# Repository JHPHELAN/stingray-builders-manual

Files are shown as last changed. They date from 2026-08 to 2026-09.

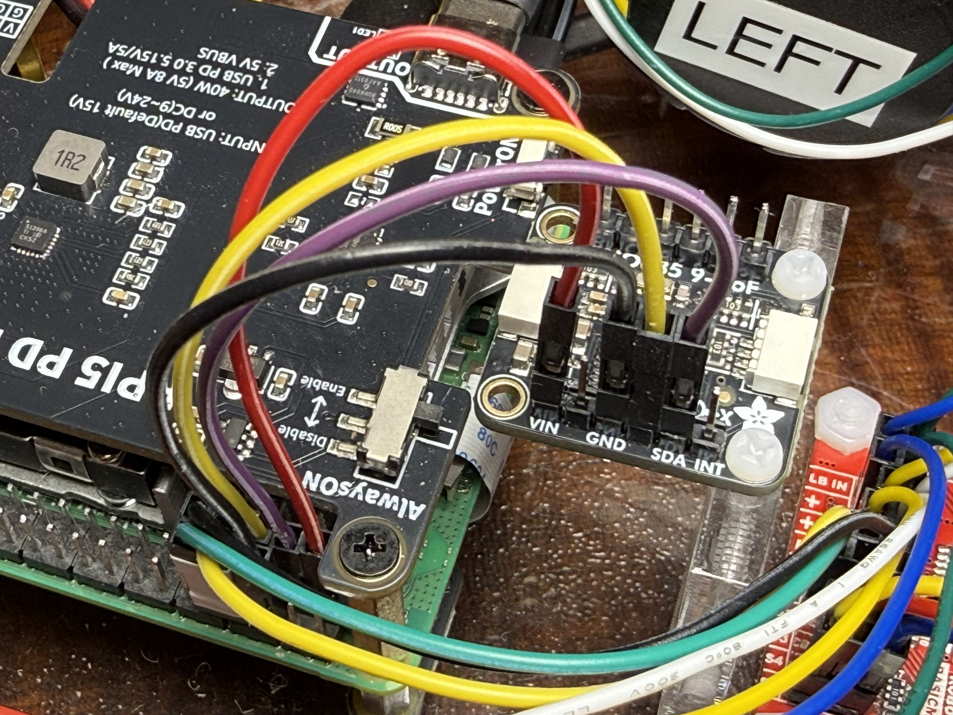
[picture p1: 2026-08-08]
images/BNO085 Wiring.jpg

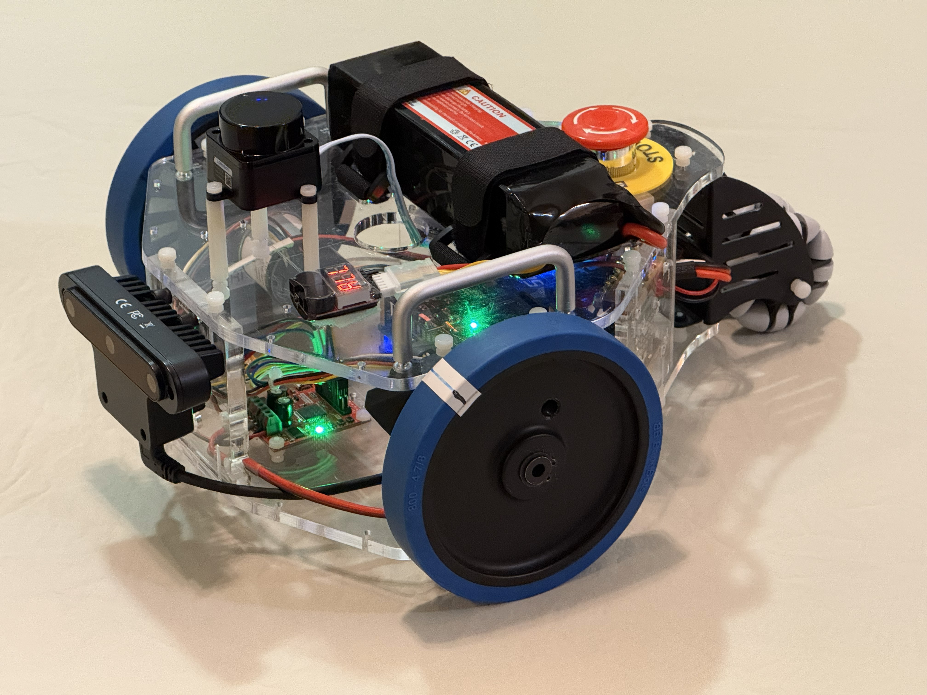
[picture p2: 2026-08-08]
images/Stormy Portrait angle.jpg

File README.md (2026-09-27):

# Stormy the Stingray - Builder's Manual

Version 1.2 - Compiled 2026-07-20; public release 2026-09-11;
amended 2026-09-21 (right rear Power Input Panel hardware caught
up: Ch 3.1 rewritten, FN 22 gains DMM verification sub-section and
15SQ045 diode part swap, Appendix G.9 schematic bumped to
2026.09.20).

If the SD card dies tomorrow, this document is how Stormy gets rebuilt.
Present-tense, imperative, subsystem-oriented.  Every procedure is one
that has been executed successfully on the real robot.

- **Owner:** James H Phelan, MD (Humble, TX).
- **Status:** Public.  Values in `<ANGLE_BRACKETS>` throughout are
  placeholders for reader-specific local values (LAN IPs, SSIDs, MAC
  addresses, house dimensions, dock offsets).  See the "Placeholder
  key" block in [`Stingray_Builders_Manual.txt`](Stingray_Builders_Manual.txt).
- **License:** CC BY 4.0 (see [License](#license) at the bottom).

## Companion files in this repo

| File | Purpose |
| --- | --- |
| [`Stingray_Builders_Manual.txt`](Stingray_Builders_Manual.txt) | **Source of truth.** Plain-text master copy of this document.  All edits go here first; `README.md` is regenerated from it (see [Regenerating this README](#regenerating-this-readme)). |
| [`Stingray_Field_Notes.txt`](Stingray_Field_Notes.txt) | 105 numbered lessons + indexes distilled from the source log.  Cited throughout the Manual by item number. |
| [`Stingray_Curation_Notes.txt`](Stingray_Curation_Notes.txt) | 17 chunks of raw stardated distillate from the source log.  Background material for the Manual. |
| [`kicad/Stingray/`](kicad/Stingray/) | KiCad 10.0 project - schematic, custom symbol library, PCB stub.  Source for Appendix [G.9](#g9--stormy-schematic-20260920png). |
| [`images/`](images/) | Diagrams and photos catalogued in [Appendix G](#appendix-g---diagrams-and-photos). |
| [`tools/build_readme.py`](tools/build_readme.py) | Regenerates this `README.md` from the `.txt`. |
| [`LICENSE`](LICENSE) | CC BY 4.0 legal text. |

The source log (`Stingray Experience.wpd`, 832 pp WordPerfect) is
**not** in this repo -- it is the private working diary this Manual
and the two companion `.txt` files were distilled from.

## Companion repositories

The Manual references code and configuration living in these repos:

- **Build descriptor:** <https://github.com/JHPHELAN/stingray>
- **Software (main):** <https://github.com/JHPHELAN/articubot_one>
    - `jp` branch -- main software (fork of slgrobotics's fork of
      Articulated Robotics' `articubot_one`)
    - `exploration` branch -- house exploration + mapping code
      (currently running on Stormy; not yet merged to `jp`)
- **Motor driver:** <https://github.com/JHPHELAN/roboclaw_driver>
    (fork of wimblerobotics/roboclaw_driver)
- **Dotfiles (private):** <https://github.com/JHPHELAN/stingray-dotfiles>

## Regenerating this README

`Stingray_Builders_Manual.txt` is the source of truth.  `README.md`
is mechanically generated from it by
[`tools/build_readme.py`](tools/build_readme.py).  To port a `.txt`
edit into the rendered manual:

```bash
python3 tools/build_readme.py
```

Then commit both files together.

## Table of contents

- [CHAPTER 0 - HOW TO USE THIS MANUAL](#chapter-0---how-to-use-this-manual)
- [CHAPTER 1 - ORIGIN](#chapter-1---origin)
- [CHAPTER 2 - CURRENT HARDWARE SUMMARY](#chapter-2---current-hardware-summary)
  - [2.1  Physical dimensions and mass](#21--physical-dimensions-and-mass)
  - [2.2  Power (see Chapter 3)](#22--power-see-chapter-3)
  - [2.3  Drivetrain (see Chapter 4)](#23--drivetrain-see-chapter-4)
  - [2.4  Compute (see Chapter 5)](#24--compute-see-chapter-5)
  - [2.5  IMU (see Chapter 6)](#25--imu-see-chapter-6)
  - [2.6  LiDAR (see Chapter 7)](#26--lidar-see-chapter-7)
  - [2.7  Camera (see Chapter 8)](#27--camera-see-chapter-8)
  - [2.8  Network (see Chapters 9 and 18)](#28--network-see-chapters-9-and-18)
- [CHAPTER 3 - POWER SYSTEM](#chapter-3---power-system)
  - [3.1  Topology (current, 2026-09-20)](#31--topology-current-2026-09-20)
  - [3.2  Emergency stop + remote kill switch (two distinct devices)](#32--emergency-stop--remote-kill-switch-two-distinct-devices)
  - [3.3  Shunt Regulator - Pololu 3779](#33--shunt-regulator---pololu-3779)
  - [3.4  Common power symptoms and fixes](#34--common-power-symptoms-and-fixes)
- [CHAPTER 4 - DRIVETRAIN](#chapter-4---drivetrain)
  - [4.1  Motors](#41--motors)
  - [4.2  Encoders](#42--encoders)
  - [4.3  Wiring - motors and encoders](#43--wiring---motors-and-encoders)
  - [4.4  RoboClaw configuration](#44--roboclaw-configuration)
  - [4.5  PID tuning](#45--pid-tuning)
  - [4.6  Driver package](#46--driver-package)
  - [4.7  Twist vs TwistStamped](#47--twist-vs-twiststamped)
  - [4.8  Per-board main-battery voltage calibration](#48--per-board-main-battery-voltage-calibration)
- [CHAPTER 5 - COMPUTE (Raspberry Pi 5)](#chapter-5---compute-raspberry-pi-5)
  - [5.1  Hardware](#51--hardware)
  - [5.2  UART configuration for RoboClaw](#52--uart-configuration-for-roboclaw)
  - [5.3  EEPROM and boot configuration](#53--eeprom-and-boot-configuration)
  - [5.4  Diagnostic commands (adopted from Sergei)](#54--diagnostic-commands-adopted-from-sergei)
- [CHAPTER 6 - IMU (BNO085)](#chapter-6---imu-bno085)
  - [6.1  Hardware](#61--hardware)
  - [6.2  Driver](#62--driver)
  - [6.3  Configuration](#63--configuration)
  - [6.4  EKF integration](#64--ekf-integration)
  - [6.5  Verification](#65--verification)
- [CHAPTER 7 - LIDAR (Youyeetoo FHL-LD19)](#chapter-7---lidar-youyeetoo-fhl-ld19)
  - [7.1  Hardware](#71--hardware)
  - [7.2  udev rule (persistent device name)](#72--udev-rule-persistent-device-name)
  - [7.3  Driver](#73--driver)
  - [7.4  Launch and static TF](#74--launch-and-static-tf)
  - [7.5  SLAM Toolbox / Nav2 usage](#75--slam-toolbox--nav2-usage)
- [CHAPTER 8 - CAMERA (Luxonis OAK-D)](#chapter-8---camera-luxonis-oak-d)
  - [8.1  Hardware](#81--hardware)
  - [8.2  Driver install](#82--driver-install)
  - [8.3  Configuration](#83--configuration)
  - [8.4  Nav2 obstacle source](#84--nav2-obstacle-source)
  - [8.5  Mesh and material](#85--mesh-and-material)
- [CHAPTER 9 - NETWORKING](#chapter-9---networking)
  - [9.1  Interfaces (current, 2026-07-20)](#91--interfaces-current-2026-07-20)
  - [9.2  Disabling wlan0](#92--disabling-wlan0)
  - [9.3  TP-Link Deco mesh layout](#93--tp-link-deco-mesh-layout)
  - [9.4  WiFi monitoring](#94--wifi-monitoring)
- [CHAPTER 10 - BASE OS INSTALL AND ROS 2 JAZZY SETUP](#chapter-10---base-os-install-and-ros-2-jazzy-setup)
  - [10.1  OS](#101--os)
  - [10.2  System updates and base tools](#102--system-updates-and-base-tools)
  - [10.3  UART configuration](#103--uart-configuration)
  - [10.4  ROS 2 Jazzy install](#104--ros-2-jazzy-install)
  - [10.5  ROS 2 environment vars](#105--ros-2-environment-vars)
  - [10.6  Additional apt packages needed](#106--additional-apt-packages-needed)
  - [10.7  SSH keys and Git](#107--ssh-keys-and-git)
- [CHAPTER 11 - WORKSPACE, REPOS, AND BUILD](#chapter-11---workspace-repos-and-build)
  - [11.1  Workspace layout](#111--workspace-layout)
  - [11.2  Clone all repos](#112--clone-all-repos)
  - [11.3  rosdep and build](#113--rosdep-and-build)
  - [11.4  Common build issues](#114--common-build-issues)
- [CHAPTER 12 - URDF AND ROBOT DESCRIPTION](#chapter-12---urdf-and-robot-description)
  - [12.1  Xacro file tree](#121--xacro-file-tree)
  - [12.2  Key physical dimensions (from stingray_properties.xacro)](#122--key-physical-dimensions-from-stingray_propertiesxacro)
  - [12.3  Wheel link split (RViz2 multi-visual bug workaround)](#123--wheel-link-split-rviz2-multi-visual-bug-workaround)
  - [12.4  base_footprint size (accounts for OAK-D nose)](#124--base_footprint-size-accounts-for-oak-d-nose)
  - [12.5  Mesh files](#125--mesh-files)
- [CHAPTER 13 - NAV2, SLAM TOOLBOX, AMCL CONFIGURATION](#chapter-13---nav2-slam-toolbox-amcl-configuration)
  - [13.1  Config files](#131--config-files)
  - [13.2  Nav2 footprint (polygon, 9-vertex)](#132--nav2-footprint-polygon-9-vertex)
  - [13.3  Heading overshoot fix (2026.04.12)](#133--heading-overshoot-fix-20260412)
  - [13.4  Costmap frequencies (Pi 5 tuning)](#134--costmap-frequencies-pi-5-tuning)
  - [13.5  KeepOut filter (for coffee-table zones)](#135--keepout-filter-for-coffee-table-zones)
  - [13.6  SLAM Toolbox](#136--slam-toolbox)
  - [13.7  AMCL (production localization)](#137--amcl-production-localization)
  - [13.8  Timestamp cache errors - diagnostic chain](#138--timestamp-cache-errors---diagnostic-chain)
- [CHAPTER 14 - MAPPING WORKFLOW (BLUEPRINT + HYBRID)](#chapter-14---mapping-workflow-blueprint--hybrid)
  - [14.1  The mapping problem](#141--the-mapping-problem)
  - [14.2  blueprint_to_pgm.py - one-time setup](#142--blueprint_to_pgmpy---one-time-setup)
  - [14.3  Room-by-room mapping cycle](#143--room-by-room-mapping-cycle)
  - [14.4  Loop closure discipline](#144--loop-closure-discipline)
  - [14.5  Loading and using the map for production nav](#145--loading-and-using-the-map-for-production-nav)
- [CHAPTER 15 - AUTONOMOUS EXPLORATION](#chapter-15---autonomous-exploration)
  - [15.1  Tool](#151--tool)
  - [15.2  Key parameters](#152--key-parameters)
  - [15.3  Known issue: cold-start deadlock](#153--known-issue-cold-start-deadlock)
  - [15.4  Usage](#154--usage)
- [CHAPTER 16 - INDICATORS](#chapter-16---indicators)
  - [16.1  Purpose](#161--purpose)
  - [16.2  Hardware (Rev 3, current)](#162--hardware-rev-3-current)
  - [16.3  Node](#163--node)
  - [16.4  WAV file preparation](#164--wav-file-preparation)
- [CHAPTER 17 - THREE-MACHINE OPERATION](#chapter-17---three-machine-operation)
  - [17.1  Machines](#171--machines)
  - [17.2  Standard launch order](#172--standard-launch-order)
  - [17.3  Common gotchas](#173--common-gotchas)
- [CHAPTER 18 - CYCLONEDDS UNICAST PEER DISCOVERY](#chapter-18---cyclonedds-unicast-peer-discovery)
  - [18.1  Why this exists](#181--why-this-exists)
  - [18.2  Config file](#182--config-file)
  - [18.3  Environment](#183--environment)
  - [18.4  Adding a third host](#184--adding-a-third-host)
- [CHAPTER 19 - DAILY OPERATIONS](#chapter-19---daily-operations)
  - [19.1  Bash aliases (~/.bash_aliases)](#191--bash-aliases-bash_aliases)
  - [19.2  Environment (~/.bashrc appended)](#192--environment-bashrc-appended)
  - [19.3  ~/.inputrc (attempted bracketed-paste fix)](#193--inputrc-attempted-bracketed-paste-fix)
  - [19.4  VS Code StormyUp task](#194--vs-code-stormyup-task)
  - [19.5  Xbox controller pairing](#195--xbox-controller-pairing)
- [CHAPTER 20 - BACKUP AND DISASTER RECOVERY](#chapter-20---backup-and-disaster-recovery)
  - [20.1  The rule](#201--the-rule)
  - [20.2  What to back up](#202--what-to-back-up)
  - [20.3  The dotfiles repo](#203--the-dotfiles-repo)
  - [20.3a  Hank Rearden (Windows) dotfiles kit](#203a--hank-rearden-windows-dotfiles-kit)
  - [20.4  NVMe full-disk backup recipe](#204--nvme-full-disk-backup-recipe)
  - [20.5  Never do this](#205--never-do-this)
  - [20.6  Off-site tier (cloud, via Hank Rearden gateway)](#206--off-site-tier-cloud-via-hank-rearden-gateway)
- [CHAPTER 21 - POST-DISASTER FULL-REBUILD RECIPE](#chapter-21---post-disaster-full-rebuild-recipe)
  - [21.1  Prerequisites](#211--prerequisites)
  - [21.2  Sequence](#212--sequence)
- [CHAPTER 22 - DIAGNOSTICS AND TROUBLESHOOTING REFERENCE](#chapter-22---diagnostics-and-troubleshooting-reference)
  - [22.1  Symptom-to-cause index](#221--symptom-to-cause-index)
  - [22.2  Zombie process cleanup drill (Field Note item 47)](#222--zombie-process-cleanup-drill-field-note-item-47)
  - [22.3  Diagnostic commands (assembled reference)](#223--diagnostic-commands-assembled-reference)
- [APPENDIX A - BILL OF MATERIALS](#appendix-a---bill-of-materials)
- [APPENDIX B - XBOX CONTROLLER MAPPING](#appendix-b---xbox-controller-mapping)
- [APPENDIX C - THE 12-BUG MOTOR-DRIVER CHECKLIST](#appendix-c---the-12-bug-motor-driver-checklist)
- [APPENDIX D - AMCL TUNING REFERENCE](#appendix-d---amcl-tuning-reference)
- [APPENDIX E - REFERENCE COMMAND CHEAT SHEET](#appendix-e---reference-command-cheat-sheet)
- [APPENDIX F - PEOPLE AND COLLABORATORS](#appendix-f---people-and-collaborators)
- [APPENDIX G - DIAGRAMS AND PHOTOS](#appendix-g---diagrams-and-photos)
  - [G.1  WIRING.jpg](#g1--wiringjpg)
  - [G.2  Shunt Regulator Diagram.png](#g2--shunt-regulator-diagrampng)
  - [G.3  Raspberry Pi GPIO pinout.png](#g3--raspberry-pi-gpio-pinoutpng)
  - [G.4  BNO085 Wiring.jpg](#g4--bno085-wiringjpg)
  - [G.5  Stormy Portrait angle.jpg](#g5--stormy-portrait-anglejpg)
  - [G.6  OSR kitspace CAD.png](#g6--osr-kitspace-cadpng)
  - [G.7  wifi_heatmap_2026-07-05.png](#g7--wifi_heatmap_2026-07-05png)
  - [G.8  wifi_drive_20260711_075912_signal.png](#g8--wifi_drive_20260711_075912_signalpng)
  - [G.9  Stormy Schematic 2026.09.20.png](#g9--stormy-schematic-20260920png)

APPENDIX F    People and collaborators
APPENDIX G    Diagrams and photos

## CHAPTER 0 - HOW TO USE THIS MANUAL

Read Chapter 1 for context.  Everything else is reference:
open the relevant chapter when working on that subsystem.

If Stormy just stopped working, jump to CHAPTER 22 (diagnostics
by symptom) and follow the pointers into subsystem chapters.

If the entire OS was lost, jump to CHAPTER 21 (post-disaster
rebuild) and work its recipe top-to-bottom.

Every claim in this Manual has a citation to either the
Stingray Experience source log (by stardate) or a companion
Field Note (by item number).  Uncited facts are current
best-known state as of 2026-09-11.

## CHAPTER 1 - ORIGIN

Stormy the Stingray is a rebuild of the Parallax Stingray
2010-era robotics platform, converted from Parallax's
proprietary Propeller board to a Raspberry Pi 5 running ROS 2
Jazzy on Ubuntu 24.04.  From the original Parallax chassis,
only the two drive-wheel motor mounts and the rear caster
support remain; the top and bottom plates and five of the
seven side plates are new laser-cut cast acrylic.  The wheels
and hex-hub adapters are original Parallax.  Everything else -
Pi, motor controller, IMU, LiDAR, camera, power system,
wiring, and all software - is new.

The project began on stardate 2023.05.06.  The full origin
chapter is preserved in Stingray_Curation_Notes.txt (CHUNK
INT-A), including the "Road to Robotics" essay and the
Blessing of the Robot ceremony from Fidelity's roll-out.
In brief: after five years chasing upgrades to the JPL Open
Source Rover Fidelity, James needed a simpler platform to
learn the principles.  The Parallax Stingray he had reviewed
for Robot Magazine (May/June 2010) fit the bill.  He found
it on a study bookshelf in a basketweave brown box he had
bought for it years earlier and forgotten.  The kit became
Stormy.

The software stack that followed was Sergei Grichine's fork
of Articulated Robotics' articubot_one, adapted to the
Stingray in simulation first and then on real hardware.

Key collaborators:

- Roberto Pensotti - retired Italian engineer, superb 3D
  draftsman and 3D printer, valued personal friend.  Fellow
  member of the Houston robotics group (Houston Robotics ->
  USAi Labs -> X-Labs at Houston City College).  Valuable
  brainstormer and collaborator on the original NASA/JPL
  Open Source Rover, on Stingray, and on many other robotics
  and AI projects.  Countless components have swapped between
  our benches over the years.

- Michael Wimble (wimblerobotics) - tutor and mentor.  Deep
  breadth from large-system design down to bit-twiddling.
  Author of the roboclaw_driver ROS 2 package Stormy uses.
  Author of the [pi5] section-header fix for
  /boot/firmware/config.txt (2025.03.05) that unblocked
  weeks of failed UART attempts.  Author of the
  `ros2-copilot-skills` library (2026.04.23, 158 SKILL files)
  that made AI-assisted ROS 2 development materially more
  productive.  Maintains the HB Robotics Knowledge Base at
  wimblerobotics.github.io.  Via Zoom-meeting collaboration:
  provided the motor_driver.cpp flat-white-wheels fix (URDF
  joint-name convention) and the startup-race-condition
  insight for the roboclaw_driver spurious over-current
  warnings.  Sounding board for years of design questions.

- Sergei Grichine (slgrobotics) - maintainer of the
  slgrobotics fork of `articubot_one` (original by Josh
  Newans / Articulated Robotics at
  github.com/joshnewans/articubot_one).  Sergei adapted
  and extended it for his own robot PLUCKY; Stormy is a
  further fork of Sergei's fork.  Also author of the
  smbus2-based BNO085 driver, the wifi_logger_visualizer,
  and other packages Stormy uses.  Offered to merge
  Stormy into his articubot_one repo as a first-class
  supported robot in 2026.01.02 - now the `jp` branch
  structure of Stormy's own fork.

- Nathan (BasicMicro) - author of the RoboClaw firmware
  and Motion Studio.  Answered several email questions
  about firmware quirks.

- HBRC ROS SIG (Home Brew Robotics Club) - the Bay Area
  robotics group whose mailing list has been the sounding
  board for hardware sourcing, debugging, and design
  decisions throughout the project.

- Pito Salas (Boston Robot Hackers) - author of the `handy`
  net_latency tool that diagnosed multi-machine ROS 2 timing
  problems.

- Roland Fields (Houston City College FabLab) - the
  laser-cutting, 3D-printing, and machining collaborator.
  He and his lab assistants provided the equipment,
  training, advice, and hands-on assistance in CAD, laser
  cutting, 3D printing, and CNC machining (including edge-
  drilling).

- HBRC members with specific contributions cited throughout
  the source log:
    - Camp Peavy - HBRC President; hosts the ROS SIG
    - Thomas Messerschmidt - animatronics and AI practitioner
      and author; hosts the AI SIG
    - Marco Walther - Mars rovers and RoboMagellan; time-sync
      and DDS advice
    - Ken Gregson - AI HAT + Orin Nano discussion
    - Chris Albertson - Wyoming Protocol + Linux Voice
      Assistant references
    - jetdillo (Steve "'dillo" Okay) - OAK-D URDF and mesh
      publisher
    - slowrunner, saiaravind19, lghrainbow - list
      contributors on multiple threads

Named AI collaborators (chronological era):

- GPT-4o, Claude-3.5-Sonnet, GPT-5, Grok - various eras,
  various results.  Claude-3.5-Sonnet was fired on
  2025.02.24 after an unrecoverable multi-file
  wreck-and-guess pattern.

- Claude Opus 4.6 - the workhorse of late 2025 through
  early 2026.  Diagnosed the 12-bug motor-driver marathon
  (2026.03.13-14).  Wrote the roboclaw_driver Command 58
  SETLOGICVOLTAGES fix (2026.03.23).  Wrote the initial
  frontier_explorer_v2.py.  Discontinued behind a $39/mo
  paywall on 2026.04.26.

- Gemini 3.1 Pro - brief transitional period 2026.04.27,
  wrote the per-SLAM xy+delta adjustment upgrade to
  merge_slam_onto_blueprint.py.

- Claude Opus 4.7 - CURRENT (as of 2026-07-20).  Wrote the
  autonomous frontier exploration that mapped the entire
  north half of the house in one run 2026.04.30.  Wrote
  the CycloneDDS unicast-peer-list fix 2026.07.10.  Wrote
  this Manual.

The pivotal event of the project is documented in Chapter 20:
on 2026.06.04 a Google Gemini-suggested rsync command wiped
Stormy's entire SSD.  The rebuild that followed is the reason
this Manual exists.  Stormy was up and running again within
a week, thanks entirely to disciplined GitHub commits and
this diary.  Do not let the same thing happen to you: read
Chapter 20 before you touch a backup command.

Milestones worth remembering:

  2023.05.06   Project start
  2024.05.06   Rediscovery in the bookshelf box; hardware
                phase begins
  2025.03.05   Michael Wimble's [pi5] config.txt fix unblocks
                UART; RoboClaw finally answers
  2025.11.10   FIRST AUTONOMOUS NAVIGATION (Nav2 + AMCL +
                SLAM Toolbox on saved map):
                https://www.youtube.com/watch?v=YAfdKwbhIpI
                (RViz2 screencast)
                https://www.youtube.com/watch?v=Kj8ijCCRR4o
                (iPhone piggyback)
  2026.03.14   12-bug motor-driver marathon fixed; Stormy
                navigates Nav2 goals house-wide on real
                hardware for the first time
  2026.04.04   Blueprint-to-PGM workflow born; map drift
                problem solved
  2026.04.30   Autonomous frontier exploration; north half
                of house mapped without joystick assist
  2026.05.08   MOTOR BURNOUT (Flag 11 realized): hair around
                left drive shaft; The Hairball Lesson
                enters the field notes
  2026.06.04   THE DATA-LOSS DISASTER; SSD wiped
  2026.06.09   Rebuild complete; back to operations
  2026.07.10   CycloneDDS unicast-peer-list fix; two-machine
                ROS 2 stable
  2026.07.11   End of source log (this Manual compiled from
                everything above)

## CHAPTER 2 - CURRENT HARDWARE SUMMARY

This chapter is the one-page "what is Stormy?" answer.
Subsequent chapters go deep on each subsystem.

### 2.1  Physical dimensions and mass

    Length overall              0.360 m
    Width overall               0.280 m
    Height (top of USB WiFi     0.305 m (highest point on
     antenna)                    the robot)
    Height (top of LiDAR)       0.180 m
    Height (top of chassis)     0.105 m (top acrylic plate;
                                does NOT include top-mounted
                                accessories: fasteners,
                                handles, stop button, battery,
                                LiDAR.  Top of OAK-D is
                                below this and not called out
                                separately.)
    LiDAR beam height           0.150 m (height of the LD19
                                scan plane above the floor;
                                NOT the base or top surface
                                of the LiDAR body)
    OAK-D lens center height    0.090 m
    Front panels tilt          29.0 deg (rotation about the
                                z-axis, out of the yz plane)
    Side panels tilt           41.7 deg (rotation about the
                                z-axis, out of the yz plane)
    Mass, fully loaded          3.284 kg (measured 2026.08.06
                                w/ battery, USB audio, USB
                                WiFi, speaker)

    Chassis body (URDF model box, no wheels/sensors):
        Length                  0.266 m
        Width                   0.228 m
        Height                  0.087 m (URDF chassis-box
                                nominal; see Chapter 12.2)
    Interior cavity height     0.076 m (measured = 3"
                                side-plate height.  Cast
                                acrylic sold online as
                                "1/4 inch" is typically
                                listed as 6 mm, and the
                                sheets used on Stormy
                                measure ~6 mm or less -
                                hence a small fudge between
                                the URDF box and reality.)
    Chassis offset             0.0455 m
    Front-panel offset          0.090 m

### 2.2  Power (see Chapter 3)

    Battery          Zeee 14.8 V (4S LiPo) 9000 mAh
    Protection       Panel-mount slow-blow fuse
                     + 15SQ045 Schottky diode pair for
                       source OR-ing (LiPo + bench-PSU
                       inputs, cathodes tied to the shared
                       bus; see FN 22 and Ch 3.1)
                     + Pololu 3779 shunt regulator
                       (17.0 V trip, on-board potentiometer
                       only; no external resistor)
    Emergency stop   Big red mushroom "bop-to-stop" on
                     stern, panel-mount, breaks the LiPo
                     bus.  Actual unit is Chinese-labelled,
                     probably originally AliExpress; the
                     JMAF listing on Amazon (B07BCY7HGN) is
                     the identical product for US sourcing.
    Remote kill      RF key-fob receiver + fob(s), mounted
                     inside the chassis near the RoboClaw,
                     wired to the RoboClaw S5 input (NOT to
                     the LiPo bus).  Kit: Amazon B08D39XWS5.
                     Not itself an "e-stop" - it is a signal
                     into the RoboClaw's S5 pin, which
                     Motion Studio labels "E-Stop" as a pin
                     mode name (see Chapter 3.2 and 4.4).
    Indicators       Headlights (2 x Eagle Eye LED 9 W 12 V)
                     Bright 12 V LED strobe (CHANZON 120pc
                     12 V 5 mm LED assortment,
                     Amazon B08G4XCQSW; the RC-car style
                     amber strobe failed - too weak, could
                     not take 12 V - and was replaced by
                     these direct-drive LEDs)
                     USB audio DAC (Sabrent USB external
                     stereo sound adapter, Amazon B00IRVQ0F8)
                     + 8 ohm 3 W speaker (Amazon B0B4D1BN4F,
                     4-pack of mini 3 W 8 ohm speakers)
                     for WAV alerts (Klingon beacon +
                     "Danger Will Robinson" on Nav2 alert)
                     All on a custom 2 x IRLZ44N MOSFET
                     direct-drive PCB from Pi GPIO 17 / 27
                     (Chapter 16).

### 2.3  Drivetrain (see Chapter 4)

    Motors           2 x Pololu #4753 (50:1 37Dx70L 12V
                     brushed gearmotor with 64 CPR encoder)
    Wheels           2 x BaneBots T81, 4-7/8" dia x 0.8" wide,
                     50A blue, hex-hub
    Wheel radius        0.0619 m (measured)
    Wheel circumference 0.389 m  (measured = calculated
                        from radius)
    Wheel separation    0.260 m  (center to center)
    Encoder          Quadrature, 3200 counts per output-shaft
                     revolution (64 CPR at motor shaft x 50:1)
    Counts per meter 8226 (from measured wheel radius)
    Caster           Rear, 0.028 m radius, at x=-0.207,
                     z=-0.035 relative to base_link
    Motor controller RoboClaw 2x7A V5c, firmware 4.2.8
                     Address 128, packet serial
                     Baud 115200
                     Per-channel current limit 2.7 A
                     Wired to Pi UART0 GPIO 14/15

### 2.4  Compute (see Chapter 5)

    Board            Raspberry Pi 5 Model B, 8 GB
                     (This is the SECOND Pi 5 - the first
                     had a broken GPIO 14 TX pin, diagnosed
                     2025.03.17 by minicom loopback test)
    Storage          Ediloca EN600 PRO NVMe SSD, 256 GB,
                     via Geekworm X1001 PCIe-to-M.2 NVMe
                     Key-M HAT for Pi 5
                     (Amazon B0CPPGGDQT)
                     (Note: Inland TN446 / Phison PS5021-E21
                     is Pi 5 INCOMPATIBLE; do not substitute)
    Power feed       52Pi PD Power Extension Board
                     (Amazon B0CYPRDY9Q)
                     - Accepts 12-24 V input
                     - Delivers 5.1 V / 5 A to Pi GPIO
                     - Always-on switch + auto-startup +
                       manual power control
    OS               Ubuntu 24.04 Noble Numbat (arm64
                     Desktop)
    Kernel           6.8.0-1057-raspi or later (raspi kernel
                     branch, NOT generic - see Field Note
                     item 7)
    ROS distro       Jazzy (with `ros-jazzy-desktop` and
                     `ros-jazzy-depthai-ros-v3`)

### 2.5  IMU (see Chapter 6)

    Chip             Adafruit BNO085 breakout
    Bus              I2C bus 1 (/dev/i2c-1)
    Address          0x4A (NOT default 0x4B)
    Driver           slgrobotics/bno08x_ros2_driver
    Mode             Game Rotation Vector (magnetometer
                     disabled; indoor use)
    Publish rate     50 Hz (was 100 Hz; halved for I2C
                     bus load)

### 2.6  LiDAR (see Chapter 7)

    Model            Youyeetoo FHL-LD19 (replaced YDLIDAR
                     X2 after 2025.11.20 belt failure)
    Interface        Silicon Labs CP2102 USB-serial adapter
    Baud             230400
    Device           /dev/ldlidar (udev symlink to ttyUSB0)
    Driver           ldrobotSensorTeam/ldlidar_ros2 (with
                     pthread.h include fix for log_module.h)
    Range            0.02 to 12.0 m (capped at 8.0 m for
                     SLAM Toolbox to reduce compute load)
    Scan topic       /scan (frame_id: base_laser)

### 2.7  Camera (see Chapter 8)

    Model            Luxonis OAK-D
    Interface        USB 3.0 direct to Pi (own USB3 port,
                     not through hub)
    Aux power        From 52Pi power board takeoff
    Driver           ros-jazzy-depthai-ros-v3 (apt)
    Point cloud      /oak/points (used by Nav2 for
                     below-LiDAR obstacle detection)
    Height band      0.02 to 0.22 m (matches Stormy's
                     collision band)

### 2.8  Network (see Chapters 9 and 18)

    Ethernet         eth0, <ROBOT_ETH_IP>, DHCP-reserved
    Internal WiFi    wlan0, DISABLED (connection.autoconnect
                     no, dev disconnect) as of 2026.07.10
                     because of Pi 5's 2.4 GHz interference
                     issues
    USB WiFi         <USB_WIFI_IFACE> (Realtek RTL8812BU
                     Amazon B078NSSM7W), <ROBOT_WIFI_IP>,
                     DHCP-reserved.
    LAN              TP-Link Deco mesh, 3 units on
                     ethernet backhaul
                     - Node A     <DECO_A_MAC>
                     - Node B     <DECO_B_MAC>
                     - Node C     <DECO_C_MAC>
    ROS domain       Default (0)
    RMW              cyclonedds (`rmw_cyclonedds_cpp`)
    Discovery        UNICAST peer list via
                     ~/cyclonedds.xml (Chapter 18)

## CHAPTER 3 - POWER SYSTEM

### 3.1  Topology (current, 2026-09-20)

    LiPo 14.8 V 9000 mAh (Zeee)
        |
        v
    Panel-mount slow-blow fuse (rated for LiPo current)
        |  (15SQ045 Schottky diode on the LiPo positive
        |   lead, cathode toward the bus - one of a pair
        |   for source OR-ing.  A second 15SQ045 lives on
        |   the bench-PSU positive lead when the bench is
        |   attached; both feed the same downstream bus so
        |   the two supplies can coexist during hot-swap
        |   without back-feeding each other.  Both diodes
        |   land in a 12-position terminal strip on the
        |   right rear Power Input Panel; see "Right rear
        |   Power Input Panel (2026-09-20, as-built)"
        |   below and Field Note item 22.)
        |
        +-- (bus-parallel, NOT in line)
        |     Pololu 3779 shunt regulator
        |     (17.0 V trip, on-board potentiometer only;
        |      dumps regenerative-braking energy as heat)
        v
    Emergency stop switch (big red mushroom on stern)
        |
        v
    Main power bus (14-16 V floating)
        |
        +-- 52Pi PD Power Extension Board -> Pi 5 USB-C
        |                                   (5.1 V / 5 A;
        |                                    52Pi board feeds
        |                                    the Pi via its
        |                                    USB-C connector,
        |                                    NOT via the GPIO
        |                                    header; also
        |                                    supplies OAK-D
        |                                    aux power through
        |                                    its takeoff)
        |
        +-- Switch -> RoboClaw main-battery input
        |
        +-- Indicators PCB (2 x IRLZ44N;
        |    Amazon B0CBKH4XGL)
        |     +- GPIO 17 -> Headlights (2 x 9 W 12 V)
        |     +- GPIO 27 -> 12 V LED strobe (CHANZON
        |     |             direct-drive assortment,
        |     |             Amazon B08G4XCQSW)
        |     +- USB audio for WAV alerts
        |                   (see Chapter 16 - INDICATORS)
        |
        +-- USB hub (power-capable but NOT currently
                     powered; runs bus-powered off the Pi
                     for now.  Feeds RTL8812BU WiFi dongle,
                     USB audio DAC, drydock kbd/mouse.
                     Powering it from the LiPo bus is still
                     open - testing needed.  The LD19 LiDAR
                     is NOT on the hub - it plugs directly
                     into a USB 2.0 port on the Pi.)

Right rear Power Input Panel (2026-09-20, as-built):
  Replaces the original panel-mount fuse holder + spade-
  connector cluster + free-form STPS-across-the-fuse
  proto-board that carried the pre-rewire hardware.  The
  new panel is mounted to the rear right side panel and
  gathers all "outside the enclosure" power and signal
  entries in one place:

    - Dual Anderson PowerPole panel-mount pair.
        Upper pair: LiPo battery input.
        Lower pair: bench power supply input.
      Both feed the same downstream bus through the
      source-OR-ing diode pair; either supply can be
      connected (or both, briefly, for graceful hand-off
      during drydock work) without back-feeding.

    - Panel-mount slow-blow fuse holder (5x20mm cartridge).
      In series with the ORed positive bus, cuts fault
      currents downstream of the diode block.

    - 12-position horizontal terminal strip.
      Carries the two 15SQ045 Schottky blocking diodes
      (one per source input, cathodes tied to the shared
      bus).  Screw terminals make the diodes field-
      replaceable without a soldering iron and give the
      DMM tidy probe points for verifying the block
      (see FN 22, "Verifying the OR-ing block with a
      DMM").

    - RJ45 keystone jack (in-panel ethernet extension).
      Runs a short internal patch to the Pi's ethernet
      jack.  Makes the wired drydock connection to Hank
      Rearden reachable at the outside of the enclosure
      without opening the top plate.

    - Green power-source indicator LED (bench input side
      only).  Wired between the bench-input POSITIVE rail
      UPSTREAM of the source-OR-ing diode and a free
      terminal-strip common NEGATIVE.  The LED body has an
      integrated current-limiting resistor (pulled from
      the multi-colour LED assortment already listed in
      the parts appendix), so no external resistor is
      needed.  When the LED is illuminated green, the
      bench PSU is actually delivering current to the
      bus; that distinguishes "plugged in but output off"
      from "plugged in and hot" (see Field Note 22
      sub-section "Bench-power indicator LED lesson"
      for why this matters).  Ferrule sizing for the
      LED's fine leads:
        * Positive end (LED lead + diode lead share one
          terminal-strip screw): black 16 AWG ferrule
          sized to accept both leads together.
        * Negative end: red 18 AWG ferrule on the fine
          LED wire, folded four times to fill the ferrule
          barrel so the terminal-strip screw has enough
          material to grip.
      No indicator on the battery input:  the LiPo has no
      output switch, so if the PowerPole is plugged in the
      source is live; there is nothing to distinguish
      from.

  Field verification of the diode block (bench, 2026-09-20):
  with only the LiPo connected, the unused bench-PSU
  PowerPole read near full bus voltage on the DMM until
  a 10 kohm resistor was placed across the probes as a
  diagnostic load; reading then collapsed to a few mV.
  See FN 22 "Verifying the OR-ing block with a DMM" for
  the divider-math explanation of why an unloaded
  reverse-biased Schottky looks like ~100 kohm to a
  10 Mohm meter input.

  Post-install hot-swap verification (2026-09-27):
  Panel assembled and successfully hot-swap tested; no
  glitch on the bus during the LiPo -> bench PSU
  handover.  The verification also caught a
  bench-PSU-specific gotcha:  on this supply, plugging
  the barrel jack into the PowerPole cable is NOT the
  same as the supply being HOT - the front-panel ON
  switch AND a separate OUTPUT button both have to be
  pushed for current to actually flow.  A first attempt
  at the hot-swap dropped the Pi because the bench PSU
  was cabled in but its output was off.  The
  green indicator LED described above was added
  immediately afterwards to make the "output live"
  state visible at a glance.  Full narrative in
  Field Note 22, "Bench-power indicator LED lesson".

  Photographs (in the stingray build repo):
    images/Power Input Panel LED front.jpg
    images/Power Input Panel LED back.jpg
    images/Power Input Side Panel LED.JPG           (LED
                              illuminated during a live
                              bench-power hot-swap test)
    images/Side Panel Wide Right Rear Fuse PowerPole Terminal Ethernet.png
    images/Power Input Side Panel Terminal Strip LED Schematic.png
  KiCad source (in this repo):
    kicad/Stingray/Stingray.kicad_sch  (top-level sheet)
    kicad/Stingray/Dual Power Input/Dual Power Input.kicad_sch

  Historical note:  the pre-rewire hardware was a small
  proto-board with four screw-terminal pairs joined by
  solder-bridged wire jumpers on the underside, carrying
  a single STPS10L25D "across the fuse," the panel-mount
  fuse holder's spade tails, and battery/bus PowerPole
  feeds.  Board was foam-taped to the rear side panel
  directly below the fuse holder.  Removed when the new
  panel was installed.

### 3.2  Emergency stop + remote kill switch (two distinct devices)

Stormy has TWO independent "stop the robot" mechanisms.
Call them by their real names and do not conflate:

(a) EMERGENCY STOP ("e-stop") - Big red mushroom "bop-to-
    stop" on the stern.  Panel-mount, normally-closed
    contact in-line with the main LiPo bus.  Pressing it
    physically breaks bus power to everything downstream
    (Pi, RoboClaw, indicators, hub).  Rated for LiPo
    current (verify before purchase).

    The actual switch on Stormy is Chinese-labelled and was
    probably originally sourced from AliExpress.  For US
    sourcing, the JMAF listing on Amazon (B07BCY7HGN) shows
    the identical product.

(b) REMOTE KILL SWITCH - RF key-fob receiver + fob,
    mounted inside the chassis near the RoboClaw.  Wired
    to the RoboClaw S5 SIGNAL PIN, NOT to the LiPo bus.
    The bus stays live; the RoboClaw halts both motors
    when it sees the S5 signal.  Kit: Amazon B08D39XWS5.

    Wiring at the receiver:
        S4 POS/NEG:    power from RoboClaw
        S5-1:          signal to RoboClaw S5 pin
        S5-NEG:        signal ground

    RoboClaw General Settings -> I/O -> S5 = "E-Stop"
    (Duty 20%, Timeout 10 s).  "E-Stop" here is
    BasicMicro's label for a Motion Studio pin mode - it
    is NOT saying this device is a real e-stop in the
    safety-engineering sense.  The real e-stop is (a)
    above.  We use BasicMicro's label unchanged because
    that is what Motion Studio calls it, and use the term
    "remote kill switch" everywhere else.

Both should be tested with motors running before every
significant demo or public run.

Why both exist: the panel-mount e-stop is the absolute
last-resort break-the-power switch.  The remote kill
switch is the friendlier "stop the robot from across the
room" affordance - it leaves the Pi and log daemons
running so you can drive back to the console and figure
out what happened.

### 3.3  Shunt Regulator - Pololu 3779

Formula (Pololu spec):
    trip_voltage = (Vbatt_nominal) * 1.10

For Stormy's 4S LiPo (14.8 V nominal, 16.1 V peak):
    16.1 * 1.10 = 17.71 V

James chose 17.0 V (conservative) on stardate 2025.12.07.
Set via the on-board potentiometer (no external resistor is
used on Stormy).  The threshold must be ABOVE any legitimate
charging voltage you might connect for balance-charging
while the shunt is wired in.

Below trip, the shunt is invisible.  Above trip, it dumps
essentially unlimited current to ground until the bus falls
back below trip.  Verify with a multimeter across the bus
during a fast deceleration.

### 3.4  Common power symptoms and fixes

Symptom: Bench PSU voltage sags below nameplate; RoboClaw
    ERR LED solid.
Cause:   Common PC-style bench supplies cannot handle the
    current surge at motor start-up and trip / sag.
Fix:     Use the LiPo battery for full-system tests, or use
    a bench supply that can actually deliver the transient
    current - e.g. Kungber 30 V 10 A adjustable DC bench
    supply (Amazon B08DJ1FDXV).  See Field Note item 16.

Symptom: Pi 5 reaches Ubuntu splash then reboots in a loop.
    "Low voltage warning" from Pi PMIC Monitor.
Cause:   Insufficient current headroom at 5.1 V rail.
Fix:     `PSU_MAX_CURRENT=5000` in rpi-eeprom-config;
    `usb_max_current_enable=1` in
    /boot/firmware/config.txt

Symptom: RoboClaw reports MBATHIGH warning at rest with 0.0 A
    current on both motors.
Cause:   Startup race - driver reads status register before
    RoboClaw finishes power-on self-test.  Documented benign
    by Michael Wimble.
Fix:     Ignore first status read on driver init (deferred
    upstream commit; see Chunk 15 flag).

Symptom: RoboClaw 3-red-blink at startup, no other apparent
    problem.
Cause:   Factory-locked LBmin = LBmax = 5.5 V on 2x7A V5c
    which has no external logic battery input; actual 3.3 V
    trips ERROR_LBATHIGH.
Fix:     James's fork of roboclaw_driver sends Command 58
    SETLOGICVOLTAGES min=0 max=140 (0.0-14.0 V) on every
    startup.  See Field Note item 97.

## CHAPTER 4 - DRIVETRAIN

### 4.1  Motors

Model:      Pololu #4753 - 50:1 Metal Gearmotor 37Dx70L mm
            12V with 64 CPR encoder
Motors:     BOTH motors were replaced as a pair on
            2026.05.13 after a left-side hair-jam burnout
            (Flag 11 - see Field Note item 26, "The
            Hairball Lesson").  Replacing both together
            minimizes configuration differences between
            the two sides.
Datasheet stall current:     5.5 A
Datasheet no-load current:   0.2 A
Continuous rating:           not published; use formula
                             continuous = stall / 3 = ~1.83 A
                             (Google-AI derivation, verified
                             empirically)

Wire identification (Pololu convention):
    Red:      Motor +
    Black:    Motor -
    Green:    Encoder GND
    Blue:     Encoder Vcc (5 V or 3.3 V; RoboClaw provides 5 V)
    Yellow:   Encoder A
    White:    Encoder B

Bundle-level labeling is NOT practical on Stormy - the
DuPont GPIO connectors at the RoboClaw end are spaced too
tightly to accept heat-shrink label tubing.  It IS worth
putting a small label on the motor body itself listing the
wire IDs (Red = M+, Black = M-, Green = ENC GND, Blue =
ENC Vcc, Yellow = A, White = B).

### 4.2  Encoders

Quadrature, 64 counts per revolution at the MOTOR shaft.
Output shaft is geared 50:1 -> 3200 counts per revolution
at the output shaft.

Counts per meter derivation (from measured wheel):
    Wheel radius:        0.0619 m
    Circumference:       2 * pi * 0.0619 = 0.389 m
                         (also measured directly around the
                         tire with a tape measure - matches
                         the radius-derived value)
    Revolutions/meter:   1 / 0.389 = 2.57 R/m
    Counts/meter:        2.57 * 3200 = 8226

Set `quad_pulses_per_meter: 8226` and
`quad_pulses_per_revolution: 3200` in the roboclaw driver
config yaml (Chapter 4.4).

### 4.3  Wiring - motors and encoders

The encoder-killer mystery.  Two RoboClaw boards appeared
to lose their M1 encoder input within days of each other in
March 2026 (Stormy's + Roberto's donor board).  An elaborate
6-part PWM-coupling / CMOS-damage hypothesis was proposed by
Claude Opus 4.6 and prescribed motor-terminal caps, series
resistors, Schottky clamps, and TVS diodes as the fix.  The
actual root cause turned out to be much simpler: Motion
Studio's General Settings / I/O / Encoder 1 Mode had
silently changed from Quadrature to ABSOLUTE.  Correcting
the setting made all symptoms disappear.  See Field Note
item 17 for the full narrative and the defensive practice.

Rule (Field Note item 17): after ANY driver work, AI-
assisted Motion Studio session, or Motion Studio version
upgrade, EXPLICITLY verify that both Encoder Modes are set
to Quadrature (Ch 4.4).

### 4.4  RoboClaw configuration

Model:              RoboClaw 2x7A V5c
Firmware version:   4.2.8 (latest for this hardware; check
                    via "ReadVersion" in Motion Studio or
                    the driver's version string on startup)
Address:            128 (packet serial)
Serial:             UART, packet serial mode
Baud:               115200 (current tested-stable value;
                    230400 also supported by the newer
                    driver but not currently in production
                    use)
Connection:         Pi UART0 (GPIO 14 TX pin 8, GPIO 15 RX
                    pin 10, common GND pin 9 or any GND)
Device name:        /dev/ttyAMA0

RoboClaw General Settings (via BasicMicro Motion Studio OR
Wimble's roboclaw_studio):

    Max Current M1:      2.7 A     (derived from Pololu #4753
                                    stall 5.5 A: stall/3*1.5)
    Max Current M2:      2.7 A
    Max Regen M1:        2.5 A
    Max Regen M2:        2.5 A
    Min Main Battery:    default   (do not set below actual
                                    LiPo minimum)
    Max Main Battery:    default
    Min Logic Battery:   0.0 V     (see Field Note item 97;
                                    set in RAM at driver
                                    startup, NOT saved to
                                    NVM)
    Max Logic Battery:  14.0 V     (see Field Note item 97)
    Serial Timeout:      0.5 s     (hardware watchdog: RoboClaw
                                    stops motors if no packet is
                                    received within this window.
                                    Was 0.0 = disabled through
                                    2026.08.08, so a killed driver
                                    node left the last commanded
                                    velocity running until the
                                    RoboClaw was power-cycled -
                                    confirmed on the drydock during
                                    the powered-hub experiment that
                                    day.  0.5 s is ~33x the driver's
                                    67 Hz odometry packet interval,
                                    so no false stops under Nav2 /
                                    SLAM load; limits runaway to
                                    ~15 cm at 0.3 m/s cruise if the
                                    driver dies.)
    Idle Delay:          1 s
    Idle Mode:           Freewheeling (flat floors + rear
                                       caster)
    Default Speed:       100%
    Default Accel:       300%/s    (was 1000%/s; 1000 was
                                    too jolty and skidded
                                    the caster)
    Default Decel:       300%/s
    S3:                  Default (unused)
    S4:                  Disabled (Duty 20%, Timeout 10 s;
                                   only matters on recovery)
    S5:                  E-Stop (Duty 20%, Timeout 10 s;
                                 wired NO contact to GND
                                 via key-fob receiver)
    CTRL1, CTRL2:        Disabled
    Encoder 1 Mode:      Quadrature (VERIFY after any driver
                                     work or AI-assisted
                                     Motion Studio session -
                                     see Field Note item 17;
                                     silent flip to "Absolute"
                                     was the root cause of
                                     the 2026.03.20 encoder-
                                     killer mystery)
    Encoder 2 Mode:      Quadrature

Save all settings to EEPROM after edits.  Power-cycle
and verify persistence.

### 4.5  PID tuning

Use BasicMicro Motion Studio's AutoTune, 10 runs per motor,
averaged.  Run each motor with the wheel OFF the ground.

Current PID values on Stormy (10-run average, most recent
autotune 2026.06.06 per the Handoff Note):

    M1 (left):
        P:      1.35657
        I:      0.19971
        D:      0.0
        QPPS:  14737   (max quadrature pulses per second)

    M2 (right):
        P:      1.12181
        I:      0.17827
        D:      0.0
        QPPS:  17381

Re-autotune after any of:
  - Motor replacement
  - Wheel replacement (radius change)
  - RoboClaw firmware update
  - Persistent "motor not tracking commanded velocity"
    symptoms

Save PID + QPPS values to
`robots/stingray/config/roboclaw.yaml` (Chapter 4.6) after
each autotune, and commit to git.

### 4.6  Driver package

Package name:   `roboclaw_driver` (NOT the older
                `ros2_roboclaw_driver`)
Upstream:       https://github.com/wimblerobotics/roboclaw_driver
Stormy's fork:  https://github.com/JHPHELAN/roboclaw_driver
                (main branch; contains Jazzy TwistStamped fix
                and Command 58 SETLOGICVOLTAGES fix)
License:        Apache-2.0

Rationale for choosing Wimble's driver over BasicMicro's
`basicmicro_ros2` (2026.03.28 shootout - see Field Note
item 93):
  - Hand-written C++, ~3700 lines, single-threaded 30 Hz
    timer loop.
  - No external Python library dependency.
  - Hardware-enforced distance-limited watchdog (motors
    auto-stop after 50 ms without new command).
  - Battle-tested on Sigyn robot.
  - Simple to audit and deploy.

BasicMicro's `basicmicro_ros2` is AI-generated Python,
~10k lines, over-engineered for diff-drive; do not switch
back.

Config file location:
    robots/stingray/config/roboclaw.yaml

Full contents (canonical):

    roboclaw_driver:
      ros__parameters:
        device_name: "/dev/ttyAMA0"
        baud_rate: 115200          # 230400 supported but
                                   # 115200 currently stable
        device_port: 128
        device_timeout: 100        # ms

        # Publishing rates
        odometry_rate: 67.0        # Hz
        joint_states_rate: 30.0
        status_rate: 10.0

        # Robot geometry
        wheel_radius: 0.0619
        wheel_separation: 0.26
        encoder_counts_per_revolution: 3200

        # Frames
        base_frame: "base_link"
        odom_frame: "odom"

        # Safety
        max_angular_velocity: 0.7
        max_linear_velocity: 0.3
        max_seconds_uncommanded_travel: 0.05

        # PID (10-run autotune average)
        m1_p: 1.35657
        m1_i: 0.19971
        m1_d: 0.0
        m1_qpps: 14737
        m2_p: 1.12181
        m2_i: 0.17827
        m2_d: 0.0
        m2_qpps: 17381

        # Motor accel
        accel: 3000

        # Publishing controls
        publish_odom: true
        publish_tf:   false        # EKF publishes odom->base_link
        publish_joint_states: true

        # Debug (keep FALSE in production)
        do_debug: false
        do_low_level_debug: false

Critical: verify the launch file loads THIS yaml, not the
driver package's default `motor_driver.yaml`.  See
stardate 2026.06.15 fix in the source log.  In
`robots/stingray/launch/stingray.drive.launch.py` around
lines 41-43:

    params_file = PathJoinSubstitution([
        FindPackageShare('articubot_one'),
        "robots", "stingray", "config", "roboclaw.yaml"
    ])

### 4.7  Twist vs TwistStamped

Nav2 in Jazzy publishes `geometry_msgs/TwistStamped`.
The full chain on Stormy must use TwistStamped end-to-end
or motors will not respond (Field Note item 36).

Verify:
    ros2 topic info -v /diff_cont/cmd_vel

Should show ONE message type: `geometry_msgs/TwistStamped`.
If two types appear, one node in the chain is on Twist and
must be updated.

Chain (all TwistStamped):
    /joy -> teleop_twist_joy (publish_stamped_twist: 'true')
    -> /cmd_vel_joy
    -> twist_mux (use_stamped: True)
    -> /diff_cont/cmd_vel
    -> roboclaw_driver_node subscribes as TwistStamped

### 4.8  Per-board main-battery voltage calibration

RoboClaw firmware exposes no user calibration for its
main-battery voltage readback.  Individual boards can show
a fixed additive or multiplicative error against a bench
voltmeter.  Stormy's 2x7A v4.2.8 reads about 1.5 V high;
without correction, low-battery cut-off logic and the
battery-status topic report bogus numbers.

Fix:  the driver applies a two-parameter linear correction
before publishing:

    reported = raw/10.0 * main_battery_scale + main_battery_offset

Defaults preserve original behavior (scale = 1.0, offset =
0.0).  Set the two YAML parameters in
`robots/stingray/config/roboclaw.yaml`:

    roboclaw_driver:
      ros__parameters:
        # Per-board voltage calibration.  Applied before
        # publishing to /battery_state.  Defaults preserve
        # the original driver readback.
        main_battery_scale: 1.0
        main_battery_offset: 0.0

Bench calibration procedure (Stormy 2026.09.04):
  1. Wheels OFF the ground, RoboClaw powered by an
     adjustable bench PSU with the LiPo unplugged.
  2. Sweep at least 8 points across the operating range
     (e.g. 12.0, 13.0, 13.5, 14.0, 14.5, 15.0, 15.5, 16.0
     V for a 4S LiPo bus).  At each point, log the true
     bus voltage (voltmeter across the RoboClaw's main
     terminals) and the driver's reported value.
  3. Fit a linear model:
         reported = m * true + b
     with least-squares regression.
  4. Invert to get calibration:
         main_battery_scale  = 1 / m
         main_battery_offset = -b / m
  5. In practice the error on healthy RoboClaws is often
     a pure additive offset (slope m = 1.0 within readback
     quantum).  Try offset-only first:  fit for
     `main_battery_offset` with `main_battery_scale = 1.0`.

Stormy 2x7A v4.2.8 calibration (bench-verified 2026.09.04):
    main_battery_scale:   1.0
    main_battery_offset: -1.525
Slope was unit within readback quantum; residual RMS at
the raw-readback quantization floor across all 8 points.
Post-calibration voltage matched the bench voltmeter to
+/- one readback quantum across the full operating range.

Feature branch status (2026-09-11):  the two parameters
live on JHPHELAN/roboclaw_driver's
`feat/main-battery-calibration` branch, commit `5d9714c`.
They are NOT yet merged to `main`.  To use them today,
either check out the branch:
    cd ~/robot_ws/src/roboclaw_driver
    git fetch origin
    git checkout feat/main-battery-calibration
    cd ~/robot_ws && colcon build --packages-select roboclaw_driver
or wait for the branch to land on main.  Delete this
paragraph and update `main` when merged.

Relation to Field Note item 97:  item 97 is about the
LOGIC-battery voltage window and SETLOGICVOLTAGES
(Command 58) - unrelated to the main-battery readback
calibration described here.  Both live on the same
RoboClaw, both in the same yaml, both are Stormy-
specific driver-startup adjustments, but they solve
different problems.  See item 97 for the logic-battery
side; this section is main-battery only.

## CHAPTER 5 - COMPUTE (Raspberry Pi 5)

### 5.1  Hardware

Board:      Raspberry Pi 5 Model B, 8 GB RAM
Storage:    Ediloca EN600 PRO NVMe SSD, 256 GB, via a
            Geekworm X1001 PCIe-to-M.2 NVMe Key-M HAT for
            Pi 5 (Amazon B0CPPGGDQT).  DO NOT substitute
            Inland TN446 / Phison PS5021-E21 (verified
            incompatible with Pi 5, 2025.03.17 log era).
Power:      52Pi PD Power Extension Board
            (Amazon B0CYPRDY9Q).  Feeds Pi from 12-24 V
            input through GPIO header at 5.1 V / 5 A.
            Always-on switch, auto-startup, manual power
            control.
Cooling:    Standard Pi 5 fan + heat sink (Pi 5
            can throttle under sustained Nav2 + SLAM load;
            monitor `sudo vcgencmd get_throttled`).

### 5.2  UART configuration for RoboClaw

The single most important Pi 5 quirk (Field Note item 34):
`/boot/firmware/config.txt` MUST use the `[pi5]` section
header for UART overlays.  Overlays under `[all]` are
silently ignored.

Correct `/boot/firmware/config.txt` snippet:

    [pi5]
    enable_uart=1
    dtoverlay=uart0-pi5
    dtoverlay=uart1-pi5    # optional; uart1 also
                            # available if needed

`/boot/firmware/cmdline.txt` MUST have `console=tty1` only.
Remove any `console=serial0,...` or `console=ttyAMA*,...`
that would put a getty on the UART.

Reboot after either change.

Verify:
    ls -l /dev/ttyAMA*
    # Should show ttyAMA0 (GPIO 14/15), ttyAMA1 (GPIO 0/1),
    # ttyAMA10.  Owned by root:dialout.
    groups
    # Should include `dialout` (add with
    # `sudo usermod -a -G dialout $USER`; requires logout)

The `ubuntu` user is added to `dialout` by default on
Ubuntu 24.04.

### 5.3  EEPROM and boot configuration

Enable full 5 A current draw:

    sudo rpi-eeprom-config --edit
    # Add:  PSU_MAX_CURRENT=5000

Also in config.txt:
    usb_max_current_enable=1

Verify after reboot:
    sudo vcgencmd get_config usb_max_current_enable
    # -> usb_max_current_enable=1

For NoMachine / headless HDMI framebuffer:

    Append to /boot/firmware/cmdline.txt (single line):
    video=HDMI-A-1:1920x1080M@60D vc4.force_hotplug=1

This makes the vc4 driver allocate a real 1080p framebuffer
regardless of physical HDMI presence, so NoMachine can
capture and stream.  Works with or without a physical
monitor plugged in.  SUPERSEDES the Chunk 16 era's dummy-
video-driver approach.

### 5.4  Diagnostic commands (adopted from Sergei)

Run these after ANY power-topology change:

    # Verify full 5 A draw allowed:
    sudo vcgencmd get_config usb_max_current_enable

    # Verify no thermal/voltage throttling occurred:
    sudo vcgencmd get_throttled
    # -> throttled=0x0 means healthy; any nonzero value
    #    indicates past or present throttling (look up bit
    #    meanings in Raspberry Pi docs)

    # Read internal PMIC rails:
    sudo vcgencmd pmic_read_adc
    # Watch EXT5V_V (should be ~5.1 V) and VDD_CORE_A
    # (typical 1.4 A under load).

    # See USB device MaxPower draws (spot the offenders):
    lsusb -v 2>&- | grep -E 'Bus 00|MaxPower'

## CHAPTER 6 - IMU (BNO085)

### 6.1  Hardware

Chip:           Bosch BNO085 (9-DOF: 3-axis accel, 3-axis
                gyro, 3-axis magnetometer with sensor fusion)
Breakout:       Adafruit BNO085 STEMMA QT breakout
Interface:      I2C bus 1 on Pi 5 (default I2C)
Address:        0x4A (NOT the default 0x4B - Stormy's
                board reports 0x4A; use i2cdetect to
                confirm)

Physical mount:  At base_link - squarely between the two
    drive motors, in the horizontal center of the robot, on
    the lower deck.  Stormy's BNO085 has its magnetometer
    DISABLED (game-rotation-vector mode, see 6.3), so
    magnetic and electrical interference from the motors
    and motor wiring is irrelevant to this IMU.

Pinout at Pi 5 GPIO header:
    Pin  3 (BLUE):    SDA  ->  BNO085 SDA
    Pin  5 (YELLOW):  SCL  ->  BNO085 SCL
    Pin  4 (RED):     VIN  ->  BNO085 VIN (3.3 V; NOT 5 V)
    Pin  6 (BLACK):   GND  ->  BNO085 GND

If i2cdetect shows no device, try swapping SDA and SCL
physical wires at the breakout - the silk-screen labels on
some breakouts are reversed (Field Note item 31).

### 6.2  Driver

Package:    `bno08x_driver`
Repo:       https://github.com/slgrobotics/bno08x_ros2_driver
Author:     Sergei Grichine (slgrobotics) fork of the stock
            driver
Rationale:  Uses `smbus2` (better I2C reliability than the
            older `smbus` library that flynneva/bno055 used).
            Reduced quaternion-norm-zero spikes and
            occasional dropped reads.

WRONG driver, do NOT confuse: `bnbhat/bno08x-ros2-driver`
(dash vs underscore in the name).  Sergei's is the correct one.

Install:
    cd ~/robot_ws/src
    git clone https://github.com/slgrobotics/bno08x_ros2_driver.git
    cd ~/robot_ws
    sudo apt install -y python3-smbus2
    rosdep install --from-paths src --ignore-src -r -y
    colcon build --packages-select bno08x_driver

Launch pattern - 2 s startup delay (2026.08.30):
    Wrap the bno085 Node in a `TimerAction(period=2.0, ...)`
    so I2C is opened AFTER the SH-2 sensor hub has finished
    booting.  Without the delay, `enable_report()` calls in
    the driver can race the hub's boot-complete signal and
    leave only ACCELEROMETER streaming - the tell is
    `imu_received_flag_` stuck at 0x02 (accel only, no gyro,
    no rotation vector).  In
    `robots/stingray/launch/stingray.sensors.launch.py`:

        from launch.actions import TimerAction
        ...
        bno085_driver_node = Node(
            package='bno08x_driver',
            executable='bno08x_driver',
            name='bno08x_driver',
            parameters=[bno085_config],
            remappings=[("imu", "imu/data")],
            respawn=True, respawn_delay=4,
            output='screen',
        )
        bno085_delayed = TimerAction(period=2.0,
                                     actions=[bno085_driver_node])
        return LaunchDescription([..., bno085_delayed, ...])

    Belt-and-braces.  The primary root-cause fix for the
    stalled-at-0x02 symptom is `enable_6dof_mode: true` in
    the yaml (see 6.3); the 2 s delay defends against the
    race that can still happen on a fast Pi 5 boot.

### 6.3  Configuration

Config file:
    robots/stingray/config/bno085_i2c.yaml

Full contents (canonical as of 2026-08-31):

    bno08x_driver:
      ros__parameters:
        frame_id: "imu_link"

        # Chassis, motors, and USB WiFi antenna prevent SH-2
        # magnetometer calibration -> 9-DOF (default) stalls
        # waiting for mag.  Force 6-DOF (accel + gyro) using
        # SH2_GAME_ROTATION_VECTOR instead of the default
        # SH2_ROTATION_VECTOR.
        enable_6dof_mode: true

        # Game-rotation-vector mode: relative orientation, no
        # absolute mag-north yaw.  Indoor use.  See Field Note
        # item 42 for the top-level-vs-nested YAML gotcha - this
        # key MUST be at top level, not under `publish.imu`.
        imu:
          use_magnetometer: false
          orientation_yaw_variance: 0.005

        # I2C interface
        i2c:
          enabled: true
          bus: "/dev/i2c-1"
          address: "0x4A"

        # Publish
        publish:
          magnetic_field:
            enabled: false       # was true; even with
                                 # use_magnetometer:false at
                                 # top level, /imu/mag
                                 # publisher still ran I2C
                                 # traffic.  Halve bus load
                                 # by disabling.
            rate: 10
          imu:
            enabled: true
            rate: 50             # was 100; EKF runs 30 Hz
                                 # so 50 is plenty

Why 6-DOF mode is mandatory on Stormy:  the SH-2 magnetic
calibration routine baked into the BNO085's on-chip sensor
fusion never completes in Stormy's magnetic environment
(motor magnets, LiPo bus currents, USB WiFi antenna).  In
default 9-DOF SH2_ROTATION_VECTOR mode, the sensor waits
indefinitely for a good calibration and never publishes a
usable orientation quaternion - `/imu/data` shows
`imu_received_flag_ = 0x02` (accelerometer only) and EKF
fusion collapses to wheel-odom-only.  `enable_6dof_mode:
true` bypasses that path entirely and uses
SH2_GAME_ROTATION_VECTOR, which is gyro + accel only.
Relative yaw drifts slowly but stays stable in the short
term, which is what SLAM loop closure handles.

Default of the driver is 9-DOF (mag-enabled) because that
is the sensor's advertised behavior for outdoor use.  Any
robot whose SH-2 mag calibration DOES complete can leave
this at default.  Stormy cannot; do not remove the pin.

### 6.4  EKF integration

Stormy uses robot_localization's EKF to fuse wheel odom
+ IMU.  Config in
`robots/stingray/config/ekf_odom_params.yaml`.

Key IMU section:

    imu0: imu/data
    imu0_config: [false, false, false,
                  true,  true,  true,    # roll, pitch, YAW
                                         # YAW=true is the
                                         # 2026.04.12 fix
                                         # for heading
                                         # overshoot
                                         # (Field Note 60)
                  false, false, false,
                  false, false, true,    # yaw_vel=true
                  false, false, false]
    imu0_differential: false
    imu0_relative: true

If you see 20-25 deg heading overshoot on Nav2 goals:
verify (a) YAW=true in row 2, and (b) `MPPI.wz_max: 0.25`
in nav2_params.yaml, and (c) `MPPI.GoalAngleCritic.
threshold_to_consider: 0.15`.  See Chapter 13 and Field
Note item 60.

### 6.5  Verification

Bench verify (before mounting):

    sudo i2cdetect -y 1
    # Should show "4a" at row 40, column a

    # DO NOT use the driver's stock launch file - it loads
    # its own default yaml with address 0x4B and will fail
    # with "BNO08x - Failed to send soft reset packet" on
    # Stormy's 0x4A board.  Point at Stormy's config yaml
    # explicitly:
    ros2 run bno08x_driver bno08x_driver --ros-args \
        --params-file /home/ubuntu/robot_ws/install/articubot_one/share/articubot_one/robots/stingray/config/bno085_i2c.yaml \
        -r imu:=imu/data \
        -r magnetic_field:=imu/mag
    # In a second terminal:
    ros2 topic hz /imu/data
    # Expected: 50 Hz average

    ros2 topic echo --once /imu/data
    # Expect flat orientation ~ [0, 0, 0.19, 0.98] (varies)
    # linear_acceleration z ~ 9.8 (gravity)

Sanity table (rotate the robot by hand; expected signs -
see Sergei's wiki, Field Note item 103):

    Flat on floor:               ax=ay~0, az=+9.8
    Tilt nose down (pitch fwd):  ax negative, az drops
    Tilt left side down (roll):  ay negative
    Nose-down gyro pitch:        gy positive
    Roll-left gyro:              gx negative
    Turn-left CCW gyro:          gz positive

## CHAPTER 7 - LIDAR (Youyeetoo FHL-LD19)

### 7.1  Hardware

Model:           Youyeetoo FHL-LD19 (LDROBOT LD19)
                 Direct-drive 360 deg TOF LiDAR
Range:           0.02 to 12 m (physical)
Sample rate:     4500 samples/second
Scan rate:       4.5 to 13 Hz
Interface:       CP2102 USB-serial adapter, 230400 baud
Power:           5 V, 300 mA max startup
Mount:           On the acrylic top plate.
                 Three 1.5" x 1/4" nylon standoffs in a
                 triangle:
                   Front:  (+x = 0.0234, y = 0)
                   Rear-R: (-x = 0.00846, -y = 0.02333)
                   Rear-L: (-x = 0.00846, +y = 0.02333)
                 Top-plate holes drilled and tapped 4-40.

Replaces:        YDLIDAR X2 (belt-driven, belt frayed 2025.11
                 and OEM replacement unobtainable).  See
                 Field Note item 28.

### 7.2  udev rule (persistent device name)

Rules file (consolidated 2026.06.29):
    /etc/udev/rules.d/99-robot.rules

Content pinning by product string + generic serial "0001":

    # LDROBOT LD19 LiDAR - CP2102 UART bridge
    SUBSYSTEM=="tty", ATTRS{idVendor}=="10c4", \
      ATTRS{idProduct}=="ea60", \
      ATTRS{product}=="CP2102 USB to UART Bridge Controller", \
      ATTRS{serial}=="0001", \
      SYMLINK+="ldlidar", MODE="0666"

    (Optional: keep the older /dev/ttyUSBLDR symlink for
     backward compatibility with any launch files that
     reference it:)
    SUBSYSTEM=="tty", ATTRS{idVendor}=="10c4", \
      ATTRS{idProduct}=="ea60", \
      SYMLINK+="ttyUSBLDR", MODE="0666"

After editing:
    sudo udevadm control --reload-rules && sudo udevadm trigger

Verify:
    ls -l /dev/ldlidar
    # -> lrwxrwxrwx 1 root root 7 ... /dev/ldlidar -> ttyUSB0

Caveat: CP2102 chips ship with generic serial "0001", so
this rule is NOT collision-proof.  If you add a second
CP2102 device, either modify one of their serials (via a
tool like `usbsn`) or pin by USB bus path instead.

### 7.3  Driver

Package:  `ldlidar_ros2`
Repo:     https://github.com/ldrobotSensorTeam/ldlidar_ros2

Install:
    cd ~/robot_ws/src
    git clone https://github.com/ldrobotSensorTeam/ldlidar_ros2.git
    cd ldlidar_ros2
    git submodule update --init --recursive

Build fix (may be needed):
    Symptom: `pthread_mutex_init` not declared in
             sdk/src/log_module.cpp
    Fix:     add `#include <pthread.h>` near the top of
             sdk/include/ldlidar_driver/log_module.h
             (may already be upstream by the time you
              clone; only apply if colcon build fails)

Build:
    cd ~/robot_ws
    colcon build --packages-select ldlidar_ros2

### 7.4  Launch and static TF

Launch file:  `ldlidar_ros2/launch/ld19.launch.py`

Modify to point at the udev symlink:

    {'port_name': '/dev/ldlidar'},
    {'serial_baudrate': 230400},

The launch file ALSO defines the static TF from `base_link`
to `base_laser`.  The LD19's convention has "forward" 90
deg RIGHT of Stormy's forward, so the TF must include a
-90 deg yaw:

    arguments=['0', '0', '0.18',
               '0', '0', '-0.7071068', '0.7071068',
               'base_link', 'base_laser']

Format is: x y z qx qy qz qw parent child.  If the LiDAR
scan appears rotated the wrong way in RViz, flip qz sign
to +0.7071068.

The physical laser plane is 0.0015 m BELOW the top of the
LD19 cylinder.  If you want RViz to show the scan at the
correct height, introduce a separate `base_laser` link in
the ldlidar.xacro sitting 1.5 mm below the visual cylinder
center.  See Field Note item 75.

### 7.5  SLAM Toolbox / Nav2 usage

Scan topic:   `/scan`
Frame ID:     `base_laser`
QoS:          BEST_EFFORT (LD19 default)

Any subscriber that requests RELIABLE will complain and get
no data.  In RViz2, set the LaserScan display's Reliability
to Best Effort.  See Field Note item 54.

SLAM Toolbox params to reduce compute load
(`robots/stingray/config/slam_toolbox_params.yaml`, key
values):

    max_laser_range:                8.0     # LD19 native 12
                                            # is overkill;
                                            # 8 is plenty
                                            # indoors
    throttle_scans:                 3       # process every
                                            # 3rd; ~3 Hz
                                            # effective
    do_loop_closing:                true    # mapping mode
    correlation_search_space_dimension: 0.5
    num_threads:                    4       # match Pi 5
                                            # cores (avoids
                                            # Ceres 50-thread
                                            # oversubscription
                                            # warning)

## CHAPTER 8 - CAMERA (Luxonis OAK-D)

### 8.1  Hardware

Model:      Luxonis OAK-D (original; NOT OAK-D Lite,
            NOT OAK-D Pro)
Interface:  USB 3.0
Cabling:    OAK-D USB cable direct to Pi 5's USB 3.0 port.
            NOT through the powered hub.  Bandwidth and
            current requirements demand direct connection.
Aux power:  Takeoff from the 52Pi power board's aux port.
            REQUIRED, not optional.  The OAK-D is a current
            hog regardless of Nav2 load; failing to supply
            aux power over-taxes the USB power rail and
            causes brown-out resets.
Built-in IMU:  BNO086.  Published as /oak/imu/data by the
            driver.  Frame_id: `oak_imu_frame`.  Location
            (0, -0.015, -0.014) m relative to camera housing
            origin, per factory calibration.  NOT used on
            Stormy - the external BNO085 is the EKF IMU,
            and James was never able to get the OAK-D's
            built-in IMU working usefully (see log notes
            for details).

Mount:  Stormy has the OAK-D horizontally centered on the
    front panel, facing forward, with its 1/4"-20 tripod
    hole positioned 1 inch below the top of the 3-inch-tall
    front panel.  Three fasteners hold it:
      - Center: a tripod-style 1/4"-20 screw threaded into
        the OAK-D's rear mounting hole.
      - Two cap-head hex screws, padded with heat-shrink
        tubing, seated in the two gaps at the top of the
        OAK-D heat sink to keep the camera level.
    This position leaves room below the camera for the USB
    data and aux-power cords.  Its RGB lens sits near
    y=+0.010, z=+0.030 relative to the front-panel origin.

### 8.2  Driver install

Use the apt package, NOT a source clone:

    sudo apt install ros-jazzy-depthai-ros-v3

The v3 suffix is CRITICAL on Jazzy 2026+ (see Field Note
item 76).  Package names ending in `_v3`:
    depthai_ros_driver_v3
    depthai_descriptions_v3
    depthai_examples_v3
Plugin class name changed: "Camera" -> "Driver"
Config file renamed: `camera.yaml` -> `driver.yaml`
YAML namespace renamed: `camera.*:` -> `driver.*:`

Any pre-2026 launch file must be renamed accordingly.  On
Stormy's articubot_one this is done in
`launch/oakd.launch.py` lines 51, 224, 225, 296, 311, 316.

### 8.3  Configuration

Slim config for Nav2 use (depth-only, low fps, filtered):

Config file:
    robots/stingray/config/oakd_nav_slim.yaml

Key parameters:

    /oak:
      ros__parameters:
        driver:
          i_pipeline_type:               "Depth"
          i_publish_tf_from_calibration: false   # let URDF
                                                  # own the TF
          i_enable_threshold_filter:     true
          # Depth threshold filter - only pass points 200mm
          # to 3000mm.  The OAK-D cannot MEASURE depth
          # closer than 200mm (though it can 'detect'
          # closer objects); the 200mm floor just matches
          # the sensor's own limit.  Rug rejection is
          # handled separately by the >20mm point-cloud
          # height clip described elsewhere.  The 3000mm
          # ceiling drops far-horizon ghost obstacles.
          i_threshold_filter_min_range:  200
          i_threshold_filter_max_range:  3000

        stereo:
          i_resolution:  "400P"    # 640x400 - low, fast
          i_fps:         5.0       # low; Nav2 refresh rate
                                    # is 5-10 Hz anyway

        rgb:
          i_enable:      false     # not used in slim mode
        left:
          i_enable:      true
        right:
          i_enable:      true

Parent frame - CRITICAL to connect the DepthAI TF tree to
the robot URDF (Field Note item 69).  In the launch args:

    parent_frame:="oakd_front_panel"
    cam_pos_x:=0.0   cam_pos_y:=0.0   cam_pos_z:=0.0

The URDF joint `oakd_joint -> oakd_front_panel` supplies
the physical position; DepthAI hangs its internal `oak`
frames under that parent.  DO NOT also declare
`oak_imu_frame` in the URDF - the driver publishes it from
factory calibration.

### 8.4  Nav2 obstacle source

Topic:     `/oak/points` (sensor_msgs/PointCloud2)
Purpose:   Detect obstacles BELOW the LiDAR plane
           (0.15 m).  LiDAR misses coffee-table crossbars,
           shoe piles, and pets.

The LOCAL and GLOBAL costmaps use DIFFERENT height bands
(learned 2026.07.06 - see Field Note item 61 for the
full rationale).  The parameter names on the point-cloud
source are `min_obstacle_height` / `max_obstacle_height`
(NOT `min_height` / `max_height` - older forks used the
short names).  Source key on both costmaps is
`oak_points` on the current live yaml.

LOCAL costmap (rolling, self-clearing):
    obstacle_layer:
      plugin: "nav2_costmap_2d::ObstacleLayer"
      enabled: True
      observation_sources: laser oak_points
      laser:
        data_type: "LaserScan"
        topic: /scan
        max_obstacle_height: 2.0
        clearing: True
        marking: True
      oak_points:
        data_type: "PointCloud2"
        topic: /oak/points
        min_obstacle_height: 0.02   # reactive - allow low
        max_obstacle_height: 0.22   # just below LiDAR
        marking: True
        clearing: True
        raytrace_max_range: 3.0
        raytrace_min_range: 0.20
        obstacle_max_range: 2.0
        obstacle_min_range: 0.20

GLOBAL costmap (non-rolling, persistent):
    Same as local EXCEPT:
      oak_points:
        min_obstacle_height: 0.10   # raise the floor
        expected_update_rate: 0.0   # silences stale warn

Rationale for the 0.10 floor on global (short version):
    A 0.02 m floor on the global map catches OAK-D stereo
    noise on carpet / tile grout / cable dust.  Because
    the global costmap is not rolling and OAK-D clearing
    only happens in its ~72 deg forward wedge, those
    phantom marks accumulate, each inflated to a ~1 m
    cost mountain by the 0.50 m inflation halo.
    Result: paralysis at doorways whose `/map` shows
    clear but `/global_costmap` shows blocked.  Raising
    to 0.10 m puts the floor above almost all
    ground-noise artifacts while still catching a shoe,
    book, or pet dish (real hazards for a ~22 cm robot).

WiFi-antenna caveat (open item, 2026-09-11):  The USB
WiFi antenna sits at 0.31 m, higher than the current
0.22 m ceiling.  When the antenna is upright, obstacles
that clear the LiDAR plane (0.15 m) but hit the antenna
are neither seen nor avoided.  Options under discussion:
raise `max_obstacle_height` to 0.35, servo-control the
antenna, or tune Nav2 recoveries to prefer rotation
over reverse.  See handoff queue for status.

Live-config sync:  2026-09-11 (nav2_params.yaml on
articubot_one exploration branch @ 96c28e5).

### 8.5  Mesh and material

Mesh file:  `articubot_one/assets/meshes/OAK-D.dae`

Two rendering-target rules:

(a) Gazebo Harmonic does NOT resolve `package://` URIs.
    Use `file://$(find articubot_one)/assets/meshes/...`
    in the URDF.  See Field Note item 70.

(b) RViz2's Ogre Collada loader takes mesh material
    ownership.  Set colors INSIDE the .dae file's
    `<library_effects>` + `<library_materials>` +
    `<bind_material>` blocks.  URDF `<material>` tags on
    `<visual>` blocks that use .dae meshes are silently
    ignored.  See Field Note item 72.

## CHAPTER 9 - NETWORKING

### 9.1  Interfaces (current, 2026-07-20)

    eth0                    Wired Ethernet, <ROBOT_ETH_IP>
                            DHCP-reserved.  Primary when
                            docked.
    wlan0                   Pi 5 internal WiFi.  DISABLED
                            since 2026.07.10 (Field Note
                            item 77 - Pi 5 2.4 GHz is broken
                            by design).
    <USB_WIFI_IFACE>         Realtek RTL8812BU USB WiFi
                            dongle on the powered USB hub.
                            <ROBOT_WIFI_IP>, DHCP-reserved.
                            Primary when driving.

DHCP reservations are set in the TP-Link Deco app for both
Stingray IPs so that CycloneDDS Peers lists (Chapter 18)
never point at a stale address.

### 9.2  Disabling wlan0

Rationale: even with route metric configured, inbound TCP
(SSH, Foxglove) still binds to whichever IP the client
dialed, and DDS multi-locator advertisement causes traffic
to leak to wlan0.  Cleanest solution is to keep wlan0 down.

    # SSH in over USB dongle IP <ROBOT_WIFI_IP> first!
    sudo nmcli con modify netplan-wlan0-<HOME_SSID> \
                          connection.autoconnect no
    sudo nmcli dev disconnect wlan0

    # Verify:
    hostname -I
    # Should show ONLY <ROBOT_WIFI_IP> (and possibly eth0's
    # <ROBOT_ETH_IP> when docked)

To re-enable if USB dongle fails:
    sudo nmcli con modify netplan-wlan0-<HOME_SSID> \
                          connection.autoconnect yes
    sudo nmcli con up netplan-wlan0-<HOME_SSID>

### 9.3  TP-Link Deco mesh layout

Three Deco units on ethernet backhaul.  All same model
(OUI <DECO_OUI>).  Radio BSSIDs = sticker MAC + 2 (2.4 GHz)
and + 3 (5 GHz):

    Location    Base MAC              2.4 GHz    5 GHz
    Node A      <DECO_A_MAC>     :<DECO_A_2G_TAIL>     :<DECO_A_5G_TAIL>
    Node B      <DECO_B_MAC>     :<DECO_B_2G_TAIL>     :<DECO_B_5G_TAIL>
    Node C      <DECO_C_MAC>     :<DECO_C_2G_TAIL>     :<DECO_C_5G_TAIL>

Node C was relocated on 2026.07.10 for better far-end
coverage.

Backhaul is ethernet on all three, so airtime is fully
available for clients - link-quality differences are not
backhaul contention.

TP-Link Deco mesh drops multicast between wired and
wireless clients.  This is the reason for the CycloneDDS
unicast-peer-list configuration (Chapter 18).

### 9.4  WiFi monitoring

Live topics (via `wifi_publisher.py` node in
articubot_one/scripts/):

    /wifi/<iface>/signal_dbm       std_msgs/Float32
    /wifi/<iface>/quality          std_msgs/Float32
    /wifi/<iface>/bitrate_mbps
    /wifi/<iface>/tx_bitrate_mbps
    /wifi/<iface>/rx_bitrate_mbps
    /wifi/<iface>/signal_avg_dbm
    /wifi/<iface>/frequency_mhz

Both wlan0 (when up) and wlxUSB publish.  1 Hz.

Node prefers `iw dev <iface> link` over `/proc/net/wireless`
because some USB drivers report dBm without the
IW_QUAL_DBM flag, causing /proc to emit garbage sentinels
(raw 1 -> -255).  Sentinel values -255.0, -256.0, 0.0 are
silently dropped.

Heat-mapping (Sergei's `wifi_logger_visualizer`, augmented
by JHPHELAN's rainbow-heatmap PR):

    ros2 launch wifi_logger_visualizer wifi_logger.launch.py
    # drive around while it runs; writes to SQLite DB

    ros2 launch wifi_logger_visualizer heat_mapper.launch.py \
         standalone:=true \
         db_path:=/home/ubuntu/robot_ws/src/wifi_logger_visualizer/wifi_data.db

Displays ROYGB rainbow heat map (red = weak, blue = strong)
overlaid on the Nav2 map in RViz2.

## CHAPTER 10 - BASE OS INSTALL AND ROS 2 JAZZY SETUP

Adopt Sergei's ROS Jazzy install guide as the reference:
    https://github.com/slgrobotics/robots_bringup

Below is the post-disaster minimum path validated on
Stormy 2026.06.09.

### 10.1  OS

Ubuntu 24.04 LTS Desktop, arm64.  From the Raspberry Pi
Imager, choose "Ubuntu Desktop 24.04.x LTS (64-bit)" and
write to the NVMe SSD via a USB-to-M.2 adapter on a
different machine, then plug the SSD into Stormy's PCIe HAT.

First boot: complete the Ubuntu setup (user `ubuntu`,
hostname `Stingray`, timezone Central US, keyboard US).

### 10.2  System updates and base tools

    sudo apt update
    sudo apt full-upgrade -y
    sudo apt install -y \
        git curl wget nano build-essential \
        python3 python3-pip \
        software-properties-common \
        gnupg lsb-release \
        htop nload hwinfo v4l-utils \
        libxcb-cursor0
    sudo add-apt-repository universe

Disable unattended-upgrades (prevents surprise ROS/kernel
updates mid-navigation):

    sudo dpkg-reconfigure unattended-upgrades
    # Choose No.

### 10.3  UART configuration

See Chapter 5.2.  Edit `/boot/firmware/config.txt` and
`/boot/firmware/cmdline.txt`.  Reboot.

### 10.4  ROS 2 Jazzy install

Add ROS 2 apt sources (using the CORRECT binary-keyring
recipe - Field Note item 38):

    sudo curl -sSL \
        https://raw.githubusercontent.com/ros/rosdistro/master/ros.asc \
        | sudo gpg --no-default-keyring \
                   --keyring /etc/apt/trusted.gpg.d/tmp.gpg --import

    sudo gpg --no-default-keyring \
        --keyring /etc/apt/trusted.gpg.d/tmp.gpg --export \
        | sudo tee /etc/apt/trusted.gpg.d/ros-archive-keyring.gpg \
        > /dev/null

    sudo rm /etc/apt/trusted.gpg.d/tmp.gpg

    echo "deb [signed-by=/etc/apt/trusted.gpg.d/ros-archive-keyring.gpg] http://packages.ros.org/ros2/ubuntu $(lsb_release -cs) main" \
        | sudo tee /etc/apt/sources.list.d/ros2.sources > /dev/null

    sudo apt update

Install Jazzy + build tools:

    sudo apt install -y \
        ros-jazzy-desktop \
        python3-colcon-common-extensions \
        python3-rosdep

Initialize rosdep:

    sudo rosdep init
    rosdep update

Set up shell:

    echo "source /opt/ros/jazzy/setup.bash" >> ~/.bashrc
    source ~/.bashrc

Verify:
    ros2 run demo_nodes_cpp talker
    # Should print "Publishing: 'Hello World: 1'" etc.
    # Ctrl-C to stop.

    # In a second terminal (or on another ROS 2 machine on
    # the same network) run the companion listener:
    ros2 run demo_nodes_cpp listener
    # Should print "I heard: [Hello World: 1]" etc.
    # (Cross-machine listener confirms DDS discovery is
    # working end-to-end.)

### 10.5  ROS 2 environment vars

Add to `~/.bashrc`:

    export RMW_IMPLEMENTATION=rmw_cyclonedds_cpp
    export CYCLONEDDS_URI=file://$HOME/cyclonedds.xml
    export LC_COLLATE=C.UTF-8            # so both machines
                                          # sort alike
    # For Gazebo Harmonic mesa/vulkan compatibility (LinuxBox):
    export QT_QPA_PLATFORM=xcb

Install cyclonedds RMW:
    sudo apt install ros-jazzy-rmw-cyclonedds-cpp

See Chapter 18 for `cyclonedds.xml` contents.

### 10.6  Additional apt packages needed

    sudo apt install -y \
        ros-jazzy-nav2-bringup \
        ros-jazzy-slam-toolbox \
        ros-jazzy-twist-mux \
        ros-jazzy-teleop-twist-joy \
        ros-jazzy-teleop-twist-keyboard \
        ros-jazzy-joint-state-publisher-gui \
        ros-jazzy-xacro \
        ros-jazzy-robot-localization \
        ros-jazzy-foxglove-bridge \
        ros-jazzy-plotjuggler-ros \
        ros-jazzy-rviz-2d-overlay-plugins \
        ros-jazzy-depthai-ros-v3 \
        ros-jazzy-gz-ros2-control \
        imagemagick-6.q16 \
        python3-smbus2

### 10.7  SSH keys and Git

Generate SSH key (accept defaults, empty passphrase):
    ssh-keygen -t ed25519 -C "ubuntu@Stingray"

Add public key to GitHub account (Settings -> SSH keys):
    cat ~/.ssh/id_ed25519.pub
    # copy the output, paste into GitHub

Configure git:
    git config --global user.name "<YOUR_NAME>"
    git config --global user.email "<YOUR_EMAIL>"

Test:
    ssh -T git@github.com

## CHAPTER 11 - WORKSPACE, REPOS, AND BUILD

### 11.1  Workspace layout

Canonical name: `~/robot_ws`

Layout:
    ~/robot_ws/
        src/
            articubot_one/          (JHPHELAN fork,
                                     exploration branch)
            roboclaw_driver/        (JHPHELAN fork, main)
            bno08x_ros2_driver/     (slgrobotics)
            ldlidar_ros2/           (ldrobotSensorTeam)
            ros_battery_monitoring/ (slgrobotics)
            scan_to_range/          (slgrobotics)
            outdoors_loc_nav/       (slgrobotics, optional)
            rviz_attitude_plugin/   (amgaber95, optional)
            wifi_logger_visualizer/ (slgrobotics + JHPHELAN
                                     rainbow-heatmap PR)
        build/                      (generated by colcon)
        install/                    (generated by colcon)
        log/                        (generated by colcon)

DO NOT keep a parallel `~/ros_ws` around.  If `.bashrc`
sources both, the older workspace's package overlays win
(Field Note item 41).  Move `~/ros_ws` -> `~/orig_ros_ws`
if you need it kept for reference, or delete outright.

### 11.2  Clone all repos

    mkdir -p ~/robot_ws/src && cd ~/robot_ws/src

    git clone git@github.com:JHPHELAN/articubot_one.git
    cd articubot_one && git checkout exploration && cd ..

    git clone https://github.com/JHPHELAN/roboclaw_driver.git

    git clone https://github.com/slgrobotics/bno08x_ros2_driver.git

    git clone https://github.com/ldrobotSensorTeam/ldlidar_ros2.git
    cd ldlidar_ros2 && git submodule update --init --recursive && cd ..

    git clone https://github.com/slgrobotics/ros_battery_monitoring.git
    git clone https://github.com/slgrobotics/scan_to_range.git
    git clone https://github.com/slgrobotics/outdoors_loc_nav.git
    git clone https://github.com/amgaber95/rviz_attitude_plugin.git
    git clone https://github.com/slgrobotics/wifi_logger_visualizer.git

### 11.3  rosdep and build

    cd ~/robot_ws
    rosdep install --from-paths src --ignore-src -r -y \
                    --skip-keys ament_python
    colcon build --symlink-install
    source install/setup.bash

Add to `~/.bashrc`:
    source ~/robot_ws/install/setup.bash

`--symlink-install` means future edits to Python scripts and
launch files take effect without a rebuild.  YAML config
files installed via `install(FILES ...)` in CMakeLists.txt
still require a rebuild (see Field Note item 40).

### 11.4  Common build issues

`ldlidar_ros2` `pthread_mutex_init not declared`:
    Add `#include <pthread.h>` to
    `sdk/include/ldlidar_driver/log_module.h`.  Rebuild.

`ldlidar_stl_ros` catkin errors:
    You accidentally cloned the ROS 1 version.  Add
    a `COLCON_IGNORE` file to prevent colcon from
    trying to build it:
        touch ~/robot_ws/src/ldlidar_stl_ros/COLCON_IGNORE
    Or delete the directory.

DepthAI v3 rename cascade:
    On ROS Jazzy after ~2026 apt updates, all depthai package
    names got a `_v3` suffix:
      depthai_ros_driver         -> depthai_ros_driver_v3
      depthai_descriptions       -> depthai_descriptions_v3
      depthai_examples           -> depthai_examples_v3
      plugin "Camera"            -> plugin "Driver"
      config file "camera.yaml"  -> "driver.yaml"
      yaml namespace `camera.*:` -> `driver.*:`
    Apply to any pre-2026 launch or yaml.  Symptom: `[launch]
    package 'depthai_ros_driver' not found`.

`ros2_roboclaw_driver` (OLD driver, 2024 era) build errors:
    You cloned the wrong driver.  Use `roboclaw_driver`
    (no `ros2_` prefix) from
    JHPHELAN/roboclaw_driver.  Delete the old clone.

Zombie topics on `ros2 topic list`:
    See Chapter 22.2 (zombie cleanup drill).

## CHAPTER 12 - URDF AND ROBOT DESCRIPTION

### 12.1  Xacro file tree

Location: `robots/stingray/description/`

    common_properties.xacro       Material colors, sim_mode arg
    stingray_properties.xacro     Physical dimensions (chassis
                                  L/W/H, wheel r, wheel sep,
                                  offsets, masses)
    robot_core.xacro              base_link, base_footprint,
                                  chassis_link (with STL mesh),
                                  wheel links (3 per wheel:
                                  tire+hub+spoke marker)
    robot.urdf.xacro              Top-level; includes all
                                  the above and all sensors
                                  and accessories

Sensor xacros:
    BNOxxx_imu.xacro              BNO085 (was BNO055; same
                                  breakout shape, renamed
                                  x -> xxx during transition)
    ldlidar.xacro                 LD19 body + support standoffs
    ldlidar_support.xacro         Standoff geometry
    oakd.xacro                    OAK-D camera body
    ros2_control.xacro            gz_ros2_control system for
                                  Gazebo sim
    Zeee_LiPo_battery.xacro       Battery block visual

Accessory xacros (added 2026.06.29):
    usb_hub.xacro                 4-port USB hub
    usb_audio.xacro               USB audio adapter
    usb_wifi_antenna.xacro        RTL8812BU antenna
    speaker.xacro                 body + cone (2 links, RViz
                                  multi-visual-material bug)
    estop.xacro                   mushroom skirt + shaft +
                                  red cap (3 links, same bug)

### 12.2  Key physical dimensions (from stingray_properties.xacro)

    chassis_length            0.266  m
    chassis_width             0.228  m
    chassis_height            0.087  m  (TODO: verify the
                                         URDF value on
                                         Stormy matches)
    chassis_offset            0.0455 m
    front_panel_offset        0.090  m  (distance the front face of
                                         the center front panel sits
                                         ahead of base_link, along +x)
    wheel_radius              0.0619 m  (measured; measured = calculated -
                                         see Chapter 4.2 derivation)
    wheel_circumference       0.389  m  (measured with tape around the tire;
                                         also = 2 * pi * wheel_radius.
                                         measured = calculated)
    wheel_separation          0.260  m  (center to center)
    wheel_thickness           0.020  m
    wheel_offset              0.130  m
    caster_radius             0.028  m
    caster_x_offset          -0.207  m
    caster_z_offset          -0.035  m
    chassis_mass              0.98   kg
    wheel_mass                0.058  kg (each)
    caster_mass               0.022  kg
    lidar_mass                0.207  kg

(Aspirational TODO: itemize the mass of every remaining
major component - Pi 5 + hat + SSD, RoboClaw, OAK-D,
battery, 52Pi board, USB hub, speaker, e-stop, front and
side acrylic panels, etc. - then subtract the sum from the
measured fully-loaded 3.284 kg to recover the residual
"incidental" mass, i.e. wiring + fasteners + everything
not broken out.)

### 12.3  Wheel link split (RViz2 multi-visual bug workaround)

Each wheel is THREE links (Field Note item 73).  In each
name below, `<wheel>` is literally either `left` or
`right`:

    <wheel>_wheel_link              Blue tire, collision +
                                     inertia here.
                                     Cylinder r=0.062, len=0.020
    <wheel>_wheel_hub_link          Black hub.
                                     r=0.054, len=0.0202
                                     (0.0001 m past each tire
                                      face to hide inner disk)
    <wheel>_wheel_marker_link       White spoke marker.
                                     Box ~0.012 x 0.018 x 0.022
                                     at y = +/- 0.7 * radius

Joined by FIXED joints (spin propagates through fixed joints
from the parent continuous-joint wheel).

CRITICAL: joint names must match what the roboclaw_driver
publishes on /joint_states.  Use `left_wheel_joint` and
`right_wheel_joint` (with `_joint` suffix), NOT the older
`wheel_left_joint` / `wheel_right_joint`.

### 12.4  base_footprint size (accounts for OAK-D nose)

    <link name="base_footprint">
      <visual name="footprint_visual">
       <origin xyz="-${chassis_offset + caster_radius} 0.0 0.0"/>
       <geometry>
        <box size="${chassis_length + (caster_radius * 2)
                    - (oakd_x_length/2)}
                   ${wheel_separation + wheel_thickness}
                   0.001"/>
       </geometry>
       <material name="shadow_gray"/>
      </visual>
    </link>

Known discrepancy (2026.06.29 hardware, not yet reflected
above): the current base_footprint box does NOT include the
rear USB hub tail added when the hub was mounted on the rear
left.  The Nav2 polygon in Chapter 13.2 was extended to
-0.278 m in x to accommodate that bulge, but the URDF
base_footprint visual still ends at the old rear.  Two
candidate fixes were considered; (b) is the chosen path
forward but is still a TODO:

  (a) Extend the base_footprint box 0.015 m to the rear:
      subtract an additional 0.015 m from the origin x AND
      add 0.015 m to the box length, so the rear edge lands
      at x = -0.278 m to match the Nav2 polygon.
      REJECTED - leaves the two-place-to-edit problem in
      place.

  (b) TODO (chosen).  Drop the box entirely and drive the
      visual off the Nav2 polygon (Chapter 13.2) so both
      stay in lockstep by construction.  Requires promoting
      the polygon into a xacro list and generating the
      visual from it, but eliminates the two-place-to-edit
      problem going forward.

### 12.5  Mesh files

Location: `articubot_one/assets/meshes/`
    OAK-D.dae
    Chassis.stl (or similar)

For Gazebo Harmonic compatibility use `file://` URIs (Field
Note item 70), not `package://`:

    <mesh filename="file://$(find articubot_one)/assets/meshes/OAK-D.dae"/>

For mesh colors: edit the .dae file itself (Field Note
item 72).  Multi-color assemblies: split into multiple
links (Field Note item 73).

## CHAPTER 13 - NAV2, SLAM TOOLBOX, AMCL CONFIGURATION

### 13.1  Config files

Location: `robots/stingray/config/`

    nav2_params.yaml              Nav2 stack
    slam_toolbox_params.yaml      SLAM Toolbox (mapping and
                                  localization modes)
    amcl_params.yaml              AMCL for production nav
    ekf_odom_params.yaml          EKF sensor fusion
    controllers.yaml              ros2_control velocity smoother
    twist_mux.yaml                twist_mux input priorities
    joystick.yaml                 Xbox controller mapping

### 13.2  Nav2 footprint (polygon, 9-vertex)

Applied to BOTH local_costmap and global_costmap in
nav2_params.yaml.  Reflects the actual stingray hull PLUS
the rear-left USB hub bulge added 2026.06.29:

    footprint: "[[0.123, 0.06], [0.06, 0.145],
                 [-0.065, 0.145], [-0.278, 0.035],
                 [-0.278, 0.015], [-0.237, -0.03],
                 [-0.065, -0.145], [0.06, -0.145],
                 [0.123, -0.06]]"

Also enable footprint awareness in MPPI:
    MPPI:
      CostCritic:
        consider_footprint: true

DO NOT combine with non-zero footprint_padding.  See
Field Note item 59.

### 13.3  Heading overshoot fix (2026.04.12)

Three-part fix (all required):

(a) In ekf_odom_params.yaml, row 2 of imu0_config:
        imu0_config: [false, false, false,
                      true,  true,  true,     # YAW = true
                      false, false, false,
                      false, false, true,
                      false, false, false]

(b) In nav2_params.yaml MPPI section:
        wz_max: 0.25             # was 0.5

(c) In nav2_params.yaml MPPI GoalAngleCritic:
        threshold_to_consider: 0.15    # was 0.5

Result: heading error 2-5 deg (was 20-25 deg).

### 13.4  Costmap frequencies (Pi 5 tuning)

Reduced to keep TF timing stable during long runs:

    local_costmap:
      update_frequency:   4.0        # was 5.0
      publish_frequency:  2.0        # was 5.0
      width:              5          # meters
      height:             5
      resolution:         0.05

    global_costmap:
      update_frequency:   1.0        # was 5.0
      publish_frequency:  1.0        # was 3.0
      width:              100        # accommodates whole house
      height:             100
      resolution:         0.05

### 13.5  KeepOut filter (for coffee-table zones)

Files:
    robots/stingray/config/keepout_mask.pgm
    robots/stingray/config/keepout_mask.yaml
    robots/stingray/launch/keepout.launch.py

In nav2_params.yaml, BOTH costmaps' plugin list:
    plugins: [..., "keepout_filter"]
    keepout_filter:
      plugin: "nav2_costmap_2d::KeepoutFilter"
      filter_info_topic: "/costmap_filter_info"
      transform_tolerance: 0.1

Launch order: SLAM Toolbox up FIRST, then
`keepout.launch.py`.  Otherwise the filter mask isn't
received.

In RViz2, the keepout mask display MUST use Reliable QoS
+ Transient Local Durability (Field Note item 49).

### 13.6  SLAM Toolbox

Config: `robots/stingray/config/slam_toolbox_params.yaml`

Key non-default parameters (Field Note item 63):

    max_laser_range:                    8.0
    throttle_scans:                     3
    do_loop_closing:                    true
    correlation_search_space_dimension: 0.5
    num_threads:                        4

Modes:
    make_map:=true       => mode: mapping (build new map)
    make_map:=false      => mode: localization (default;
                            use saved posegraph)

Save aliases (in `~/.bash_aliases` on Stingray):

    savemap() {
        local n="${1:-Stormy}"
        ros2 service call /slam_toolbox/save_map \
          slam_toolbox/srv/SaveMap \
          "{name: {data: /home/ubuntu/robot_ws/src/articubot_one/assets/maps/${n}}}"
    }

    savegraph() {
        local n="${1:-Stormy}"
        ros2 service call /slam_toolbox/serialize_map \
          slam_toolbox/srv/SerializePoseGraph \
          "{filename: /home/ubuntu/robot_ws/src/articubot_one/assets/maps/${n}}"
    }

    loadgraph() {
        local n="${1:-Stormy}"
        local x="${2:-0.0}"; local y="${3:-0.0}"; local t="${4:-0.0}"
        ros2 service call /slam_toolbox/deserialize_map \
          slam_toolbox/srv/DeserializePoseGraph \
          "{filename: /home/ubuntu/robot_ws/src/articubot_one/assets/maps/${n},
            match_type: 2,
            initial_pose: {x: ${x}, y: ${y}, theta: ${t}}}"
    }

Theta convention: counterclockwise from +X (map East)
toward +Y (map North).  See Field Note item 44.

### 13.7  AMCL (production localization)

Config: `robots/stingray/config/amcl_params.yaml`

Tuning that handles Stormy's feature-poor open-area (Field Note item 64):

    max_particles:            5000
    laser_max_beams:           120
    laser_likelihood_max_dist: 4.0
    alpha1..alpha4:            0.1
    update_min_d:              0.05
    update_min_a:              0.05

### 13.8  Timestamp cache errors - diagnostic chain

"Message Filter dropping message: frame X ... timestamp
earlier than transform cache" - check in this order (Field
Note item 66):

    1. use_sim_time=true anywhere on real hardware.
       grep all launch files.
    2. Cross-machine time skew (chrony / systemd-timesyncd).
       Verify with Pito Salas's `handy net_latency`.

       One-time install (both hosts):

           cd ~/ros_ws/src
           git clone https://github.com/Boston-Robot-Hackers/handy.git
           cd ~/ros_ws
           colcon build --packages-select handy
           source install/setup.bash

       Runs as a matched pair: on one host you start the
       "node1" side of the pair, on the other host the
       "node2" side.  Each side subscribes to its partner's
       topic and prints the observed time skew.  Direction
       matters - run both directions to see round-trip
       symmetry:

           # On Stingray, in one terminal:
           ubuntu@Stingray:~/ros_ws$ ros2 run handy net_latency node1 node2
           [INFO] ... [node1_delay_node]:
               Node started: subscribing to node1_topic,
               publishing to node2_topic
           Time skew from node2 to node1 is 7.16 ms

           # On LinuxBox, in another terminal:
           ubuntu@LinuxBox:~/ros_ws$ ros2 run handy net_latency node2 node1
           [INFO] ... [node2_delay_node]:
               Node started: subscribing to node2_topic,
               publishing to node1_topic
           Time skew from node1 to node2 is 3.47 ms

       Interpretation: single-digit-millisecond skew in
       either direction is healthy for Nav2 + TF.  Tens of
       milliseconds points at a chrony / systemd-timesyncd
       misconfiguration on one host.  Hundreds of ms will
       spontaneously break TF caching and Nav2 controllers
       even before any IMU / DDS issue.
    3. DDS implementation mismatch across machines.
       Both must be `RMW_IMPLEMENTATION=rmw_cyclonedds_cpp`.
    4. IMU driver hangs / quaternion-norm-zero spikes.
       Use Sergei's smbus2 BNO055/BNO085 fork.

## CHAPTER 14 - MAPPING WORKFLOW (BLUEPRINT + HYBRID)

### 14.1  The mapping problem

Piecemeal SLAM mapping accumulates drift, leading to pinched
doorways that AMCL can't traverse.  Solution: use the
architect's blueprint as the geometric backbone, overlay
SLAM-observed furniture on top.

Two scripts do the work:

    articubot_one/assets/maps/blueprint_to_pgm.py
    articubot_one/assets/maps/merge_slam_onto_blueprint.py

### 14.2  blueprint_to_pgm.py - one-time setup

Inputs (specific pixel dimensions depend on your export;
the values shown are placeholders):
    <BLUEPRINT>_WallsOnly.jpg        CorelDraw export of
                                     walls-only layer;
                                     <Px_W> x <Px_H> CMYK
    <BLUEPRINT>_XMarksDock.jpg       Same base image with
                                     a green cross at the
                                     robot dock location

CorelDraw scale factor (adjust to your drawing):
    <drawing_in> in in drawing = <life_in> in in life
    drawing_dist = life_dist * (<drawing_in> / <life_in>)

Blueprint image resolution (from your export):
    Source width       = <Px_W> px
    Real-world width   = <H_ft> ft  =  <H_m> m
    Source resolution  = <H_m> / <Px_W>  m/px

Target Nav2 resolution: 0.05 m/px (matches all other maps
on Stormy).  Output PGM is downscaled from the source PX
grid to the Nav2 PX grid via `cv2.INTER_AREA` (preserves
thin walls).

Dock origin calibration:
    Green cross at pixel (<gx>, <gy>) in source image.
    x_origin = -<gx> * <res_mpp>                = <-x_m>
    y_origin = -(<Px_H> - <gy>) * <res_mpp>     = <-y_m>
    (bottom-left corner of the output PGM in map frame)

Then hand-tune 0.5 m at a time via relaunch-and-observe
cycles until Stormy's LIDAR returns overlay the blueprint
walls.  The final `origin` for the map's YAML is a
per-house calibration value.

Placeholder legend (substitute your own):
    <Px_W>, <Px_H>    Source blueprint pixel dimensions
    <H_ft>, <H_m>     House width feet, meters
    <res_mpp>         <H_m> / <Px_W>  in m/px
    <gx>, <gy>        Pixel location of green cross (dock)
    <-x_m>, <-y_m>    Computed map-origin offsets

Door handling:
    All interior doors passable EXCEPT two closet doors,
    which are closed by painting wall pixels across the
    doorway post-flood-fill.

Run:
    cd ~/robot_ws/src/articubot_one/assets/maps
    python3 blueprint_to_pgm.py

Outputs:
    Stormy_blueprint.pgm
    Stormy_blueprint.yaml
    Stormy_blueprint.png

Commit outputs to git.

### 14.3  Room-by-room mapping cycle

Bash aliases assumed (Chapter 19).

    Terminal 1:  joy         # joystick; typically launched on
                             # LinuxBox because the Xbox USB
                             # receiver lives there and sends
                             # /joy over WiFi.  Launch on
                             # Stingray instead when the robot
                             # is stuck and you need to walk
                             # behind it with the pad to steer
                             # it out or back to the dock.
    Terminal 2:  stingln slam:=true  # bringup in mapping mode
    Terminal 3:  (used for loadgraph / savegraph / merge)

Cycle:
    (1) Load previous best posegraph:
            loadgraph Stormy_v<NN> 0.0 0.0 0.0
    (2) Drive ONE room manually with joystick.  Slow speed
        (0.2 m/s cruise, 0.5 m/s turbo).
    (3) Save posegraph and PGM:
            savegraph Stormy_v<NN+1>
            ros2 run nav2_map_server map_saver_cli \
                 -f ~/robot_ws/src/articubot_one/assets/maps/Stormy_v<NN+1> \
                 --ros-args -p map_subscribe_transient_local:=true
    (4) Merge SLAM PGM onto the blueprint:
            cd ~/robot_ws/src/articubot_one/assets/maps
            python3 merge_slam_onto_blueprint.py <NN+1>
    (5) Kill SLAM launch, redock Stormy, test with AMCL:
            AMCLtest

Optional cleanup between (4) and (5):
    - FileZilla `Stormy_merged.png` to Hank Rearden (Windows)
    - Windows Paint: erase ghost obstacles by painting
      value 205 (unknown) or 254 (free) over them
    - FileZilla back to Stormy
    - Convert PNG -> PGM:
          convert Stormy_merged.png Stormy_merged.pgm

CRITICAL: DO NOT re-run `merge` after cleaning - it
overwrites the cleanup with the raw SLAM data again.

### 14.4  Loop closure discipline

Field Note item 56: SLAM Toolbox only corrects accumulated
drift on LOOP CLOSURE.  Before every `savegraph`, drive
BACK through areas you already scanned.  In RViz2 you will
see the map SNAP as loop closure fires - THAT is the signal
to save.

Skipping this and saving after a one-way trip out to a new
room bakes drift into the posegraph permanently.

### 14.5  Loading and using the map for production nav

    ros2 launch articubot_one stingray.launch.py \
        localizer_type:=amcl \
        map:=/home/ubuntu/robot_ws/src/articubot_one/assets/maps/Stormy_merged.yaml

Both `localizer_type` and `map` are LaunchConfiguration args
(configurable from CLI).  Default is
`localizer_type:=amcl` and default map is Stormy_merged.

The `AMCLtest` alias wraps this command.

## CHAPTER 15 - AUTONOMOUS EXPLORATION

### 15.1  Tool

Package:   articubot_one/scripts/frontier_explorer_v2.py
Launch:    articubot_one/launch/explore.launch.py
Config:    articubot_one/robots/stingray/config/explore.yaml
Alias:     `explore`

Node subscribes to /map, computes frontier clusters
(4-connected flood fill on FREE cells at unknown-boundary),
scores them by cluster size + distance + clearance, sends
top-scored frontier as a Nav2 goal, waits for success/abort,
repeats.  Stops when no reachable frontier remains.

Deep-dive:  a long-form explanation of the scoring, filters,
recovery, and known limitations of `frontier_explorer_v2.py`
lives in the README of the `exploration` branch of
JHPHELAN/articubot_one:
    https://github.com/JHPHELAN/articubot_one/tree/exploration
The write-up was originally requested by Sergei Grichine on
behalf of Michael Wimble at an HBRC Zoom meeting; ChatGPT
authored it from the source file, and it was lightly
reformatted for GitHub Markdown.  Read it before tuning
parameters below.

### 15.2  Key parameters

In explore.yaml (edit and rerun; six most-used params also
overridable on CLI):

    min_cluster_size:         6        # min frontier cells
    min_clearance_m:          0.40     # halo around goal
    near_goal_distance:       1.0
    max_path_detour_ratio:    3.0      # reject 4-7x detours
    blacklist_radius_m:       0.8      # after failed goal
    min_unknown_pocket_cells: 25       # skip already-
                                       # characterized pockets
    goal_cost_check:          true     # pre-check goal cell
                                       # against global costmap
    goal_max_cost:            90       # reject inflated cells
    cluster_score_cap:        20
    distance_score_weight:    5.0      # doubles cost of
                                       # each meter
    clearance_score_weight:   4.0
    dry_run:                  false    # true = don't actually
                                       # send goals

Goal-yaw computation (2026.05.18):  _make_goal_pose uses
`atan2(dy, dx)` so Stormy arrives already pointed in the
direction of travel; no "spin to face east" at every goal.

### 15.3  Known issue: cold-start deadlock

At the dock, if the initial map view yields no candidates
that pass all filters, the robot sits still, SLAM Toolbox
has no new motion to update the map, no new candidates
appear.

Workaround: nudge Stormy with the joystick to break the
deadlock.  Fix (deferred): send a small in-place rotation
goal after N consecutive cycles produce zero candidates.

### 15.4  Usage

Terminal 1:   joy
Terminal 2:   stingln slam:=true
              (wait ~40 s for SLAM Toolbox + Nav2 to settle)
Terminal 3:   loadgraph Stormy_ckpt_<timestamp> 0.0 0.0 0.0
Terminal 4:   anchorln         # optional; publish waypoint
                                # markers to RViz2
Terminal 5:   explore

Save checkpoints frequently:
    savegraph Stormy_v<NN>

Kill explorer with Ctrl-C in its terminal.  Return Stormy
to dock manually before quitting SLAM.

## CHAPTER 16 - INDICATORS

### 16.1  Purpose

Headlights, amber LED strobe, and WAV audio playback for
robot state feedback.  Xbox controller buttons for manual
control.  Automatic AUDIO-ONLY alerts on Nav2 aborts and
recovery-node RUNNING events (the amber strobe is not
tied to Nav2 events - it is manual only, via the Y button).

### 16.2  Hardware (Rev 3, current)

Circuit board:  JLCPCB-fabricated protoboard, ~$55 total
                delivered.  Two IRLZ44N logic-level MOSFETs
                direct-driven from Pi GPIO (no NPN inverter
                stage).

Pinout (canonical, matches exploration-branch
indicators.yaml):
    Pi pin  2 (5V, orange)         -> +5V rail
    Pi pin  9 (GND, orange/white)  -> GND rail
    Pi pin 11 (BCM 17, blue)       -> Ch1 MOSFET gate
                                      -> Headlights (2x Eagle
                                         Eye 9W 12V)
    Pi pin 13 (BCM 27, blue/white) -> (unused on Rev 3;
                                       was the LED line in
                                       earlier Rev 3 wiring)
    Pi pin 15 (BCM 22, green)      -> Ch2 MOSFET gate
                                      -> Amber LED strobe
                                      (GPIO 22 was the Rev 2
                                       piezo; on Rev 3 the
                                       LED line moved here
                                       and the piezo is
                                       gone - audio is now
                                       the USB DAC + speaker
                                       below.)

Each MOSFET channel:
    Pi GPIO -> 220 ohm series -> Gate
                                    |
                                   10k ohm pulldown to GND
                                    |
                                   Drain -> load ( - )
                                   Source -> GND (common
                                             with Pi GND)

Load side (both channels):
    +12V (LiPo bus) -> load ( + ) -> load body -> Drain

Boot polarity: GPIO defaults to INPUT (high-Z, effectively
low) at boot; pulldown pulls gate low; load is OFF.
Node then powers headlights ON as a boot-running-light,
then OFF after `headlights_startup_on_sec` (default 3 s).

Audio hardware:
    USB-to-3.5mm audio dongle (Amazon B00IRVQ0F8)
    Mini 8 ohm speaker (Amazon B0B4D1BN4F)
    Plugged into Pi USB 2.0 port via powered hub.

Amber LEDs:
    4 orange 5mm LEDs bundled with white (22 AWG) ferrules,
    mounted in 5mm holes drilled through the acrylic
    top plate.  Edge-glow effect across the whole top.
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

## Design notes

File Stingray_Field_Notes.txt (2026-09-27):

================================================================
STINGRAY FIELD NOTES
================================================================
Lessons, symptom-to-cause mappings, and principles distilled from
three years of Stormy the Stingray's development (2023.05.06 -
2026.07.11).

Purpose:  a working engineer's field manual - what NOT to do,
          what to do INSTEAD, and why.  Each item is a
          hard-won lesson from the source log (Stingray
          Experience.wpd, 832 pp).  Every item cites the
          stardate it was learned so you can trace context.

Companion file:  Stingray_Curation_Notes.txt has the raw
                 stardated entries and full context.
                 Stingray_Builders_Manual.txt has the
                 forward-looking "how to rebuild" reference.

Style:  plain text.  No markdown.  "====" as dividers.
        Written to be pasted into anything.
================================================================

================================================================
PART I - THE AI-IN-LOOP DISCIPLINE
================================================================

AI is a colleague, not an oracle.  Every lesson in this section
was purchased with real time or real hardware.

--------------------------------------------------------------
1.  ***THE CONTEXT.TXT DISCIPLINE***  (2026.03.04)
    Long AI chats silently overflow the model's context window.
    Once overflowed, the AI's answers become plausible-but-wrong
    with no warning.  DEFENSE: keep a `context.txt` file that
    lists your hardware, OS, workspace layout, and the current
    problem.  Attach it at the START of every new chat AND
    reattach whenever you switch topics.  Ask the AI to suggest
    additions as you go.  This IS why James invented the
    practice; cite it.

--------------------------------------------------------------
2.  ***NEVER RUN AN AI-GENERATED DESTRUCTIVE COMMAND WITHOUT
    --DRY-RUN FIRST***  (2026.06.04 - the disaster)
    Google Gemini AI Overview produced an `rsync` recipe that RECURSIVELY
    COPIED the destination into itself, wiping Stormy's entire
    SSD.  Rule: for `rsync`, `dd`, `cp -r`, `find ... -delete`,
    any partition op - RUN WITH `--dry-run` FIRST.  Read the file
    list.  Confirm src and dst one more time.  Only then drop
    `--dry-run`.  This is not paranoia; it's how you keep your
    project alive.

--------------------------------------------------------------
3.  ***`rsync` TRAILING-SLASH RULE***  (2026.06.04)
    `src/` copies the CONTENTS of src into dst.
    `src` (no slash) copies src DIRECTORY nested inside dst.
    AI-generated `rsync` examples routinely get this wrong.  This
    is the single most common cause of recursive-copy disasters.

--------------------------------------------------------------
4.  ***"YOU'RE FIRED!" PATTERN***  (2025.02.24 origin)
    When an AI's multi-file edits leave you worse off than before
    - stop iterating with the same AI.  Revert every `.bak` from
    the failed session (`git restore .`).  Start over with a
    different model or a human.  Do not brute-force through it.
    Multi-file edits with no corresponding new understanding =
    revert-and-walk-away.

--------------------------------------------------------------
5.  ***DO NOT USE AI FOR TROUBLESHOOTING***  (2026.02.21 keystone
    - James's own headline, preserve verbatim)
    Field Note headline, from James, after wasting two weekends
    with VSCode / GPT-5.2-Codex and Grok Code Fast 1:
      "Yesterday and today wasted with VSCode / GPT 5.2 Codex
       & Grok Code Fast 1
       DO NOT USE AI FOR TROUBLESHOOTING.  NEVER!"
    Interpretation:  AIs are great at CODE-WRITING when you know
    the answer.  They are poor at DIAGNOSING unknown misbehaviors
    where hallucinated fixes cascade.  For diagnostic problems,
    read logs yourself first.  Ask a HUMAN expert.  Use AI only
    once you have a hypothesis you want to test.

    Exception noted by James 2026.07.26:  "Present company
    Claude Opus 4.7 excepted.  Extended context and self-
    reflection has much improved troubleshooting.  You've yet
    to mess me up."  Field-Note translation: the rule applies
    to AIs of the GPT-4o / Grok / Sonnet-3.5 generation and
    to short-context sessions.  With Opus-class models and
    disciplined session hygiene (context.txt, condensed
    recaps, handoff notes - items 1, 11, 15), AI-assisted
    troubleshooting has become genuinely useful.  Re-
    evaluate the rule per generation of model, not once and
    for all.

--------------------------------------------------------------
6.  ***VERIFY WHICH MODEL YOU ARE ACTUALLY TALKING TO***
    (2026.06.08)
    Poe / Copilot / VSCode all can silently swap the model
    beneath you (expired session, tier downgrade, retired
    version).  A GPT-4o answer given while you thought you were
    talking to Claude-Opus is worse than useless.  Symptom: prior
    context vanishes; suggestions contradict yesterday's plan.
    Fix: look at the model name in the reply header EVERY reply.
    If you find your dialog partner has been replaced, start
    over with a fresh chat plus your context.txt.

--------------------------------------------------------------
7.  ***AI CROSS-BOUNDARY CAUTION - BOOT/KERNEL/EEPROM/PARTITION
    IS SACRED***  (2025.11.27 CP210x saga)
    When an AI-suggested fix crosses a "boot integrity" boundary
    - kernel install, initramfs regen, EEPROM edit, partition
    table change - STOP and audit.  Ask if there's a SHORTER
    path first.  Example: Copilot suggested installing
    `linux-generic-hwe-24.04` (which has no Pi 5 device
    tree blob and would have bricked the Pi) to get a
    CP210x driver, when a simple
    reboot into the already-installed newer raspi kernel worked.

--------------------------------------------------------------
8.  ***AI OVERCOMPLICATION IS A CODE SMELL***  (2025.12.08)
    When an AI proposes a NEW node/service/plugin to solve a
    problem that could be a config change in an existing file -
    the AI has lost the plot.  Example: Copilot proposed a bespoke
    "IMU (Inertial Measurement Unit) correction node" for OAK-D
    axis alignment; the real fix
    was setting `parent_frame:=oakd_front_panel` in the launch
    args.  Shortest fix path that touches the fewest files is
    nearly always right.

--------------------------------------------------------------
9.  ***AI-GENERATED OFFICIAL DRIVERS ARE STILL AI-GENERATED***
    (2026.03.28 - the driver shootout)
    Even when a hardware manufacturer publishes a "current"
    official driver, check its provenance.  BasicMicro's
    `basicmicro_ros2` states in its header:
      "Author: Generated by Claude Code"
    Its 18300 lines of mock-based tests exercise the AI's
    understanding of the protocol, NOT real hardware behavior.
    Wimble's hand-written 3700-line C++ `roboclaw_driver`
    (battle-tested on Sigyn) is preferable.  For any hardware-
    in-the-loop code, prefer battle-tested-by-a-human over
    AI-generated.

--------------------------------------------------------------
10. ***OWN A LOCAL AI AS A NO-CLOUD FALLBACK***  (2026.03.01;
    DOWNGRADED 2026.07.26)
    Install GPT4All from nomic.ai + a small local model like
    Phi-3 Mini Instruct.  Runs entirely offline.  When the cloud
    LLM misbehaves, expires, or hits a rate limit, the local
    fallback is still there.

    Downgrade note (James 2026.07.26):  "Not sure this is
    valid.  Local LLMs are severely limited and of little
    use in the situations we're discussing."  Locally-hosted
    small models are far behind cloud Opus-class models on
    the kind of debugging and integration tasks this project
    generates.  Keep GPT4All or an equivalent installed as a
    hedge against a total-internet-outage day, but do NOT
    plan to use it as a working substitute for the cloud AI.
    Its practical role is: "the internet is down and I need
    to look up a bash flag," not "help me diagnose why Nav2
    is dropping timestamps."

--------------------------------------------------------------
11. ***HANDOFF-NOTE DOCTRINE***  (2026.05.15 / 2026.06.06)
    End every AI session by asking: "In PLAIN TEXT, summarize
    what we accomplished, list what's still open, and save
    yourself a memory file at
    `/memories/session/<yyyy-mm-dd>-<topic>.md`.  Give me the
    full path."  Paste the summary into your project log.
    Reference the memory-file path at the START of the next
    session ("read /memories/session/... and continue").  This
    preserves continuity without replaying the whole dialog.

--------------------------------------------------------------
12. ***CROSS-CHECK AI PIN AND WIRE ASSIGNMENTS AGAINST THE
    DATASHEET BEFORE POWERING UP***  (2025.02 Grok GPIO)
    Grok gave GPIO pin assignments that would have shorted rails
    to signals.  Every AI-produced wiring diagram gets one
    pass with the physical device datasheet in one hand before
    the LiPo goes anywhere near it.

--------------------------------------------------------------
13. ***A NEW AI PROPOSING MULTIPLE FILE EDITS WITH NO NEW
    UNDERSTANDING = REVERT***  (2026.02.21)
    Symptom: "Now try this."  "That didn't work?  Try this."
    "That didn't work?  Try this."  If between attempts the AI
    is not explaining WHY the previous attempt failed and WHAT
    that teaches about the system, it's guessing.  Guessing
    across N files leaves you N files-worth of wreckage.
    `git status`, `git restore .`, walk away.

--------------------------------------------------------------
14. ***THE "AUTHOR: GENERATED BY <MODEL>" LINE IS A CODE
    SMELL***  (2026.03.28)
    If code in a manufacturer's official repo declares AI
    authorship, look extra hard at whether it's been HARDENED
    on real hardware.  Mock-based tests validate that the code
    matches the AI's understanding of the protocol, not that it
    works on physical devices in your specific environment.

--------------------------------------------------------------
15. ***KEEP AI CHATS SHORT AND FOCUSED - CONTINUITY IS
    EXPENSIVE***  (2026.05.31, verbatim from James's HBRC
    testimony)
    The ENTIRE thread gets processed with each new query.  A
    weekend of chatty debugging can blow through a month's AI
    budget.  Rules:
      - one issue per chat
      - reset with a fresh chat + context.txt when the topic
        changes
      - end every chat with the handoff-note discipline
        (item 11)

================================================================
PART II - ELECTRICAL
================================================================

--------------------------------------------------------------
16. ***SCAVENGED PC POWER SUPPLY + BUCK CONVERTER =
    INRUSH TRAP***  (2025.09.29; scope corrected 2026.09.06)
    A scavenged desktop-PC ATX power supply (or similar
    fixed-output brick pressed into service as a bench PSU)
    cannot source the inrush surge a buck converter demands
    when charging its input caps.  Symptom: RoboClaw's
    main-battery voltage reads far below the nameplate;
    RoboClaw ERR LED solid.
    Fix: use the LiPo battery for full-system tests, OR use
    a real adjustable bench PSU with current-limit and
    transient headroom.  Stormy uses a Kungber 30 V 10 A
    adjustable DC bench supply (Amazon B08DJ1FDXV, purchased
    2026 precisely to solve this problem) with no inrush
    issues since installed.
    Scope note (James 2026.09.06):  a true adjustable bench
    PSU does NOT exhibit this failure - the original wording
    ("many bench PSUs") over-generalized from the scavenged
    PC brick that motivated the note.  The failure mode is
    specific to fixed-output PC-style supplies, not to
    laboratory bench PSUs.  A scavenged PC brick is fine
    only for isolated components with no buck converter
    inline.

--------------------------------------------------------------
17. ***CHECK MOTION STUDIO ENCODER MODE ON BOTH CHANNELS
    AFTER ANY AI OR DRIVER SESSION***  (2026.03.20-21;
    ROOT CAUSE CONFIRMED 2026.07.26)
    The "encoder-killer mystery" - two RoboClaw boards that
    appeared to lose their M1 encoder input within days of
    each other - turned out to be NEITHER electrical damage
    NOR cable-coupling.  Root cause CONFIRMED (James
    2026.07.26) is that Motion Studio's General Settings /
    I/O / Encoder 1 Mode had silently changed from Quadrature
    to ABSOLUTE.  Root cause of the setting change itself
    never found; strong suspects are a stray write from an
    earlier AI-assisted Motion Studio session or an autosave
    collision.

    Symptoms (all consistent with an encoder configured in
    the wrong mode, NOT with damage):
      - Nav2 goal produces the honey-bee dance: left wheel
        jiggles ~1/8 rev, right wheel tries to turn.
      - In Motion Studio drydock: rotating the wheel by
        hand, encoder value sticks at 0 when stopped or
        latches near ~2035 (suspiciously close to HALF of
        3200 counts per revolution).
      - Swapping the M1 and M2 encoder cables at the
        RoboClaw does NOT move the fault - the wrong-mode
        setting is on the RoboClaw side.
      - Autotune on M1 diverges; only power-cycle stops
        the motors.

    Fix (30 seconds if you know to check):
      Motion Studio -> General Settings -> I/O ->
      Encoder 1 Mode: change from Absolute to QUADRATURE.
      Encoder 2 Mode: verify also QUADRATURE.
      Write to RoboClaw.  Power-cycle.  Retest.

    Defensive practice (the ACTUAL Field-Note principle):
      After ANY driver work, ANY AI-assisted Motion Studio
      session, or any Motion Studio version upgrade,
      EXPLICITLY verify that both Encoder Modes are set to
      Quadrature.  Do it before you power the motors and
      before you launch Nav2.  This one 5-second check is
      worth two RoboClaw boards' worth of frustration.

    Cross-references (this is why the check matters):
      - Item 8 (AI overcomplication is a code smell).  The
        original Claude Opus 4.6 diagnosis of the same
        symptoms proposed an elaborate 6-part cable-PWM
        (pulse-width modulation) coupling / CMOS-damage
        chain with caps, series resistors, Schottky clamps
        and TVS (transient voltage suppression) diodes.  All
        plausible in isolation; NONE the actual cause.
        When an AI diagnosis is complex, look for the
        simple setting-change explanation FIRST.
      - Item 40 (config edit didn't take effect).  Same
        family of failure: the running system is not what
        you think it is because a setting somewhere has
        silently changed.

    Historical note:  Earlier versions of this Field Notes
    file (through 2026.07.26 morning) described PWM coupling
    into encoder wires as the proven cause of the two-board
    incident and prescribed physical wire separation + caps
    + clamp diodes as the fix.  That description is
    withdrawn.  Physical separation of motor and encoder
    wires remains reasonable general practice (it costs
    nothing) but was NOT what solved the encoder-killer
    mystery on Stormy.  See stardate 2026.03.20-21 in the
    source log for the full narrative arc, including
    Claude Opus 4.6's hypothesis and Roberto's donor board
    exhibiting the same symptoms.

--------------------------------------------------------------
18. ***SHUNT REGULATORS PROTECT THE POWER BUS, NOT SIGNAL-
    LEVEL INPUTS***  (2026.03.21; scope corrected 2026.07.26)
    General principle worth remembering:
    The Pololu 3779 shunt regulator on Stormy handles regen
    voltage spikes on the LiPo bus.  It does NOT protect any
    signal-level input (encoder lines, I2C, UART, GPIO) from
    anything.  Signal-level protection is a separate design
    problem: series resistors + clamp diodes, TVS, opto-
    isolation, or shielded/twisted routing.
    (This item originally motivated the item-17 elaborate
    encoder-line protection scheme.  With the encoder-killer
    mystery now RESOLVED as a Motion Studio setting change -
    see item 17 - this note stands on its own as a general
    principle, not as a specific mitigation.)

--------------------------------------------------------------
19. ***THE PI 5 OFFICIAL 5.1V/5A PSU CAN BE KILLED BY POWERED-
    HUB INRUSH***  (2025.11.30)
    ANKER powered USB hub + Pi 5 + accessories (LD19 + OAK-D +
    keyboard) drew enough peak current at 5.1V to sag the PSU
    into repeated brownout, and eventually killed it.  Symptoms:
    Pi reaches Ubuntu splash, then reboots in loop; scope shows
    no visible sag at buck-converter output; Pi PMIC (power
    management IC) Monitor reports "low voltage warning".  Fix
    chain:
      - `PSU_MAX_CURRENT=5000` in EEPROM
      - `usb_max_current_enable=1` in `/boot/firmware/config.txt`
      - 52Pi PD Power Extension Board becomes the canonical Pi
        feed (SUPERSEDES the USB-C jack)
      - Keep a spare OFFICIAL CanaKit PSU on hand.

--------------------------------------------------------------
20. ***WIRE GAUGE FROM MEASURED PEAK CURRENT, NOT
    NAMEPLATE***  (2025.11.30; scope corrected 2026.09.06)
    Size wire from the peak current a load will actually
    draw, not from its continuous rating or its supply's
    nameplate.  A motor rated 2 A continuous can spike to
    5.5 A stalled (item 21); a buck converter charging its
    input caps can transiently pull far more than its
    steady-state feed (item 16).
    Gauges installed on Stormy today (representative of the
    current build, NOT a fixed spec - each build should
    measure its own peaks and choose accordingly):
      LiPo bus (peaks up to 15 A):   14 AWG
      Bus -> RoboClaw:               14 AWG silicone
      Bus -> headlight switch:       20 AWG
    Stormy has no standalone buck converter in the power
    path - the 52Pi PD Power Extension Board is the Pi's
    only regulator (item 24; see Manual Chapter 3.1 for the
    authoritative topology).  If you add a buck converter
    downstream of the LiPo, size its feed for the inrush
    its input caps will pull, not for the load's continuous
    draw.
    Scope note (James 2026.09.06):  the original wording
    presented these gauges as "Rules Stormy uses" - they
    are actually what happens to be installed today, not
    a house standard.  An earlier draft also carried a
    "many bags of '12-16V robot wire' are undersized"
    quip; provenance unclear and not from James, so
    removed.

--------------------------------------------------------------
21. ***ROBOCLAW CURRENT LIMIT DERIVES FROM MOTOR STALL, NOT
    DRIVER HARDWARE MAX***  (2026.05.13 - the hairball lesson,
    hard version)
    Formula:
      continuous ~= stall / 3
      limit      = continuous * 1.5
    Pololu #4753: stall 5.5A -> continuous 1.83A -> limit 2.7A.
    Setting the RoboClaw's per-channel limit near its 7A
    hardware max (6.5A on Stormy pre-fix) lets a stalled motor
    cook itself before the overcurrent trip fires.  This IS
    Flag 11 - the motor burnout of 2026.05.08.  See also
    item 26 (The Hairball Lesson).

--------------------------------------------------------------
22. ***POWER PROTECTION: FUSE + SOURCE-OR-ING DIODES +
    SHUNT REGULATOR***  (2025.12.07 install of 3779;
    external-resistor guidance added 2026.07.26; STPS role
    corrected 2026.09.06; hardware caught up on right rear
    Power Input Panel with 15SQ045 diode pair 2026-09-20)
    Panel-mount slow-blow fuse: cuts fault currents on the
    shared bus.
    15SQ045 Schottky diodes - SOURCE OR-ING FOR HOT-SWAP:
    one on the LiPo positive lead, one on the bench-PSU
    positive lead, both cathodes tied to the shared bus.
    Purpose is source OR-ing so battery and bench PSU can
    both be attached (drydock work) without either back-
    feeding the other.
    Pololu 3779 shunt regulator (17.0 V trip on 4S LiPo,
    ONBOARD adjustable pot sets the trip threshold; NO
    external shunt resistor on Stormy): dumps regenerative-
    braking energy to ground on the bus.
    Light-robot back-EMF budget:  on a ~3.2 kg indoor robot
    that decelerates over a fraction of a second, the
    energy the drivetrain returns to the bus is small
    enough that the 3779 shunt alone handles it.  No
    braking-resistor bank, no dedicated dump load.  A
    heavier or faster platform should verify with a scope
    across the bus during a hard decel and add resistance
    if the shunt's trip point stays clamped.

    When to add the OPTIONAL external shunt resistor:
      The onboard adjustable trims the TRIP THRESHOLD (bus
      voltage at which the MOSFET turns on).  The external
      resistor (typical 1 ohm, 25 W wirewound) is where the
      regenerative energy is actually DISSIPATED AS HEAT.
      Without one, the MOSFET dumps current through its own
      on-resistance and heats up.  That is fine for BRIEF
      regen spikes (typical light-robot indoor decel,
      milliseconds at a time).  Add the external resistor
      only if you have SUSTAINED regen - heavy robot, long
      high-speed decels, or you find the shunt MOSFET running
      hot to the touch after a run.  On Stormy at 3.2 kg and
      typical indoor speeds, none needed.  Rule: install the
      external resistor only when the shunt MOSFET gets hot
      in normal use.

    Scope note (James 2026.09.06 -> hardware caught up
    2026-09-20):  earlier wording described a single
    STPS10L25D "across the fuse" as a fuse-blown-
    case backup.  That was never the actual role.  The real
    arrangement is a source OR-ing PAIR (one Schottky on
    each input's positive lead) so battery and bench PSU
    can coexist during hot-swap without back-charging each
    other.  Manual Chapter 3.1 topology annotation and
    notes updated in the 2026.09.06 pass.  Physical rewire
    installed on Stormy 2026-09-20 as the right rear Power
    Input Panel; see Manual Ch 3.1 "Right rear Power Input
    Panel (2026-09-20, as-built)" and the four assembly
    photographs in the stingray build repo
    (images/Power Input front.png,
    images/Power Input rear.png,
    images/Side Panel Wide Right Rear Fuse PowerPole Terminal Ethernet.png,
    images/Power Input Side Panel Terminal Strip Schematic.png).

    Part-number footnote:  STPS10L25D (10 A / 25 V, TO-220
    dual, common-cathode) was the pre-rewire design intent
    and appears in earlier Manual revisions and the source
    log through 2026.09.06.  Installed on 2026-09-20 is
    15SQ045 (15 A / 45 V, DO-27 axial single).  Both are
    low-Vf Schottky rectifiers suitable for source OR-ing.
    The 15SQ045 was chosen for higher I/V margin (the 4S
    LiPo bus is 14.8 V nominal but peaks near 16.8 V at
    full charge; the STPS's 25 V rating is thin) and for
    its axial form factor that plugs directly into the
    12-position terminal strip on the new panel without a
    heat sink or dead-bug soldering.

    Verifying the OR-ing block with a DMM (James + Sergei,
    2026-09-20):  with the LiPo connected but no downstream
    load turned on, a modern DMM probing the UNUSED bench-
    PSU PowerPole reads near full bus voltage.  That is
    not a diode failure - it is the meter's own ~10 Mohm
    input impedance forming a voltage divider with the
    reverse-biased Schottky, which itself looks like
    ~100 kohm of leakage impedance with no other load:
         Vmeter = Vbus x (10 Mohm) / (100 kohm + 10 Mohm)
                ~= 0.99 x Vbus
    The reading is caused by a few microamps of leakage
    current, not real bus current flowing through the
    diode.  Diagnostic fix: put a 10 kohm resistor across
    the DMM probes.  The 10 kohm swamps the meter's
    10 Mohm and the divider collapses:
         Vmeter = Vbus x (10 kohm) / (100 kohm + 10 kohm)
                ~= 0.09 x Vbus at worst
         Real reading (leakage-limited): a few mV.
    A few-mV reading confirms the block is intact.  In
    normal operation the downstream load is ohms to
    hundreds of ohms, not megohms, so no phantom voltage
    appears at the unused input during real use.  Keep a
    10 kohm 1/4 W resistor with the DMM probe leads for
    future source-OR verifications.  Credit to Sergei
    (slgrobotics) for the tip.

    Bench-power indicator LED lesson (James, 2026-09-27,
    post-install hot-swap test):  The Panel was
    hot-swap-tested by connecting the bench PSU cable to
    the bench PowerPole while the LiPo was still on, then
    pulling the LiPo.  On the first attempt the Pi died.
    Cause was NOT the diode block - it was operator error
    on the bench PSU.  The supply used here (a
    programmable bench unit) treats "cable plugged in" and
    "output enabled" as two separate states: the front-
    panel ON switch AND a distinct OUTPUT button both have
    to be pushed before current flows.  A visual check of
    the barrel jack and PowerPole is not enough to confirm
    the bus has a live second source.
    Fix (installed same day): a green LED with an
    integrated current-limiting resistor (from the
    multi-colour LED assortment already in the parts
    inventory - see Manual BOM section) wired between the
    bench-input POSITIVE rail UPSTREAM of the source-OR-
    ing diode and a free terminal-strip common NEGATIVE.
    LED illuminated green means the bench PSU is actually
    delivering current; LED dark means the cable is
    plugged in but the supply is not outputting.  The
    battery input needs no such indicator: the LiPo has
    no output switch, so "plugged in" and "hot" are the
    same state.
    Ferrule practice for the LED's fine leads:
      * Positive end (LED lead shares a terminal-strip
        screw with the diode lead): black 16 AWG ferrule
        sized to accept both leads together.
      * Negative end: red 18 AWG ferrule on the fine LED
        wire, folded four times to fill the ferrule
        barrel so the terminal-strip screw has enough
        material to grip.
    See Manual Ch 3.1 "Green power-source indicator LED"
    for the same wiring detail in the panel description,
    and the LED-illuminated photograph in the stingray
    build repo (images/Power Input Side Panel LED.JPG).

--------------------------------------------------------------
23. ***REVERSED-POLARITY SANITY TEST***  (2026.03.21)
    After adding an inline diode in a battery lead, VERIFY
    orientation before turning power on: REMOVE the fuse; try
    to power up.  If power flows anyway, the diode is backward.
    If no power flows, replace fuse and proceed normally.

--------------------------------------------------------------
24. ***52Pi HAT SUPERSEDES BUCK CONVERTER FOR PI 5 CLEAN
    POWER***  (2025.11.30)
    The 52Pi PD Power Extension Board (Amazon B0CYPRDY9Q)
    accepts 12-24V input, delivers 5.1V/5A to the Pi 5's GPIO
    header, and has always-on + auto-startup + manual power
    control.  Cleaner than "buck converter into USB-C jack" -
    dedicated regulator + short traces to the header pins.

--------------------------------------------------------------
25. ***KEEP A SPARE POWERED USB HUB - FAILURE MODE IS
    SILENT***  (2026.06.15)
    USB hub port 2 died with no warning; devices plugged in
    simply didn't enumerate, other ports worked.  Replacement
    turnaround from Amazon is ~2 days.  Keep at least one spare
    on hand.

================================================================
PART III - MECHANICAL
================================================================

--------------------------------------------------------------
26. ***THE HAIRBALL LESSON***  (2026.05.08 - Flag 11 realized)
    Domestic-floor robots live in a hairball habitat.  Hair
    winds around drive shafts and caster wheels.  A wound-up
    drive shaft raises the effective load beyond the motor's
    continuous rating.  If your overcurrent limit is too
    permissive (item 21), you cook the winding.  RULES:
      - Check drive shafts and caster wheels for hair
        BEFORE EVERY drive session.
      - "Take a lesson from your vacuum cleaner and check
        for hairballs." (James, verbatim)
      - Combine with item 21 (proper current limit) so a
        detected hair-jam trips the overcurrent cut-off
        before winding damage.

--------------------------------------------------------------
27. ***CAST ACRYLIC ONLY FOR LASER CUTTING - NEVER
    EXTRUDED***  (2026.01.10)
    Extruded acrylic (cheap Amazon) MELTS at the laser kerf
    into a beaded gummy mess.  Cast acrylic vaporizes cleanly.
    Suppliers must LIST "cast acrylic" explicitly in writing.
    FabLab / Roland's stock is 1/4" cast, works reliably; 3/8"
    is marginal for laser but usable at low speeds; extruded
    is never usable.

--------------------------------------------------------------
28. ***BELT-DRIVEN LIDAR IS A WEAR ITEM***  (2025.11.20)
    The YDLIDAR X2's drive belt frayed and broke on Stormy
    around 2025.10; OEM replacement belt was unobtainable; an
    O-ring jury-rig failed within weeks.  Direct-drive LiDARs
    (Youyeetoo FHL-LD19) have no drive-train to wear out.  For
    a robot that lives indoors and gets driven a lot, prefer
    direct-drive LiDAR from the start.

--------------------------------------------------------------
29. ***OFFICIAL POWERWERKS POWERPOLE CRIMPER IS WORTH THE
    PRICE***  (2026.01.11)
    Alternative crimpers, generic pliers, spade connectors -
    all fussy and unreliable at power-bus currents.  Buy the
    real Powerwerks tool once; use it for the life of the
    robot.

--------------------------------------------------------------
30. ***HAND-TAPPING 4-40 IN 1/4" CAST ACRYLIC WORKS FINE***
    (2026.01.11)
    Standard hand tap in a pilot-drilled hole; go slow, back
    out every half-turn.  Small drill press adequate for edge-
    drilling.  You don't need a CNC drill unless you have
    dozens.

--------------------------------------------------------------
31. ***BNO085 BREAKOUT SDA / SCL LABELS MAY BE SWAPPED***
    (2026.01.16)
    If `i2cdetect -y 1` shows no device at 0x4A after wiring
    per the silk-screen, try swapping the SDA and SCL physical
    wires.  Not a datasheet-visible fact; discovered by
    experiment.

--------------------------------------------------------------
32. ***PLACE THE IMU AS FAR AS POSSIBLE FROM MOTORS AND
    WIRES***  (Sergei Grichine 2026.01.13, verbatim;
    scope-qualified 2026.07.26; mount-location corrected
    2026.09.11)
    "Placing IMU in between the wheels/motors on a real robot
     is a bad idea.  I place IMUs as far as possible from other
     components, wires - everything.  I also check mag field
     with a real compass - the arrow should point North when
     the robot turns."
    On Stormy the Adafruit BNO085 breakout lives at
    base_link - squarely between the two drive motors, on
    the lower deck, same location as the BNO055 it
    replaced.  This IS Stormy's authoritative IMU.  Do NOT
    confuse it with the BNO086 that lives INSIDE the OAK-D
    camera housing:  that second IMU was tried, never worked
    on Stormy, and is abandoned (Field Note item 68).  Any
    references elsewhere to "the BNO085 on the OAK-D
    front-panel deck" are the abandoned OAK-D IMU, not the
    real one.

    Scope note (James 2026.07.26):  "This is only relevant
    if the magnetometer/compass on the IMU is being used,
    which in general it should not."  With the magnetometer
    OFF (as on Stormy - game rotation vector mode), the
    compass-check portion of Sergei's rule does not apply,
    and the placement rule matters less than it does with
    the mag on.  Keep the physical distance as a general
    good practice (accels/gyros benefit from reduced motor
    vibration coupling) but do NOT treat this as a mag-
    interference workaround when the mag is disabled.

    Canonical mag-disable configuration (2026.08.31):  the
    two-yaml-key pattern to disable the magnetometer on
    slgrobotics/bno08x_ros2_driver is documented in Manual
    Chapter 6.3 - `enable_6dof_mode: true` at the top level
    (bypasses SH-2 mag calibration) AND
    `imu.use_magnetometer: false` (game rotation vector
    mode).  See also items 42 (YAML nesting gotcha), 95
    (which slgrobotics fork), 103 (the sanity-check wiki).

--------------------------------------------------------------
33. ***USB-B PORTS FAIL SILENTLY - KEEP A SPARE HUB***
    (2026.06.15)  See item 25.

================================================================
PART IV - SOFTWARE & CONFIG TRAPS
================================================================

--------------------------------------------------------------
34. ***PI 5 CONFIG.TXT REQUIRES THE `[pi5]` SECTION HEADER***
    (2025.03.05 - Michael Wimble's fix, saved days of Grok
    frustration)
    Overlays placed under `[all]` in `/boot/firmware/config.txt`
    are silently ignored on Pi 5.  You MUST use:
        [pi5]
        dtoverlay=uart0-pi5
        enable_uart=1
    Grok tried the same overlay under `[all]` for weeks with no
    effect.  This is the single most important Pi 5 quirk to
    know.

--------------------------------------------------------------
35. ***NAV2 FOOTPRINT MUST BE AN INLINE STRING, NOT A YAML
    LIST***  (2025.10.10)
    WRONG (parse error "Sequences cannot be key"):
        footprint:
          - [-0.24, -0.14]
          - [-0.24,  0.14]
          - [ 0.10,  0.14]
          - [ 0.10, -0.14]
    RIGHT (inline string):
        footprint: "[[-0.24, -0.14], [-0.24, 0.14],
                     [0.10, 0.14], [0.10, -0.14]]"
    Apply to BOTH local_costmap and global_costmap.

--------------------------------------------------------------
36. ***`geometry_msgs/Twist` vs `TwistStamped` IS A SILENT
    TYPE-HASH MISMATCH***  (bit Stormy 2026.03.14, 2026.03.16,
    2026.06.20 - THREE times)
    Nav2 in Jazzy publishes TwistStamped.  If your motor driver
    subscribes to Twist, twist_mux quietly bridges nothing.
    Symptom: joystick + twist_mux + driver all "running", motors
    don't move, `ros2 topic info -v /diff_cont/cmd_vel` shows
    two message types on the topic.
    Fix everywhere in the chain:
      - `teleop_twist_joy`: param `publish_stamped_twist: 'true'`
        (LOWERCASE - see item 37)
      - `twist_mux`: `use_stamped: True` in both launch args
        and node params
      - motor driver subscribes to `TwistStamped`
    On the Wimble roboclaw_driver fork, this is a 4-edit fix
    in the .hpp + .cpp.

--------------------------------------------------------------
37. ***YAML `'True'` (CAPITAL T IN A STRING) IS SILENTLY
    `False`***  (2026.03.14)
    Symptom: `publish_stamped_twist: 'True'` in a launch file
    ARG behaves as if False was passed.  Cause: ROS parses the
    string-with-capital-T as the literal string, which then
    fails the bool coercion.
    Rule: always use lowercase `'true'` or `'false'` inside
    quotes.  Or drop quotes entirely for boolean scalars in
    YAML - true/false without quotes work correctly.

--------------------------------------------------------------
38. ***ROS 2 APT KEYRING MUST BE BINARY .gpg, NOT ASCII
    ARMOR***  (2026.06.08 - post-disaster rebuild)
    Piping `ros.asc` (ASCII PGP block) into a `.gpg` file
    triggers:
        E: Conflicting values set for option Signed-By ...
        != -----BEGIN PGP PUBLIC KEY BLOCK-----
    Correct recipe:
        sudo curl -sSL https://raw.githubusercontent.com/ros/rosdistro/master/ros.asc \
             | sudo gpg --no-default-keyring \
                        --keyring /etc/apt/trusted.gpg.d/tmp.gpg --import
        sudo gpg --no-default-keyring \
                 --keyring /etc/apt/trusted.gpg.d/tmp.gpg --export \
             | sudo tee /etc/apt/trusted.gpg.d/ros-archive-keyring.gpg > /dev/null
        sudo rm /etc/apt/trusted.gpg.d/tmp.gpg
    In short: re-export ASCII -> binary via `gpg --import | gpg
    --export | tee`.

--------------------------------------------------------------
39. ***`sudo` DOES NOT EXTEND PAST A PIPE***  (2025.11.23)
    WRONG:
        sudo dd if=/dev/nvme0n1 bs=4M | gzip -1 > /media/.../file.gz
                                                     ^ Permission denied
                                                       (shell redirect
                                                        runs as your user)
    RIGHT:
        sudo sh -c 'dd if=... | gzip -1 > /path/file.gz'
      or:
        sudo dd if=... | gzip -1 | sudo tee /path/file.gz > /dev/null
    Same principle for `>>`, `<`, `< <(...)`.

--------------------------------------------------------------
40. ***YOUR ON-DISK CONFIG YAML IS NOT WHAT THE RUNNING NODE
    SEES***  (2026.01.19)
    Symptom: edit `~/robot_ws/src/.../foo.yaml`, relaunch,
    behavior unchanged.  Cause: the running node loads from
    `~/robot_ws/install/.../share/.../foo.yaml`, which is the
    COPY produced by `colcon build`.  Fix: rebuild after every
    config edit:
        cd ~/robot_ws && colcon build --packages-select articubot_one
    Or use `--symlink-install` so future edits pick up
    immediately (but even then, ONLY for source files that are
    symlinked, not yaml files installed via `install(FILES ...)`).

--------------------------------------------------------------
41. ***OLD WORKSPACE STILL-SOURCED-IN-BASHRC TRAP***
    (2026.03.09)
    Symptom: "why is my new driver behaviour identical to the
    old one?"  Cause: `.bashrc` still has
    `source ~/ros_ws/install/setup.bash` BEFORE
    `source ~/robot_ws/install/setup.bash`.  First-sourced
    package overlays win.
    Fix: `mv ~/ros_ws ~/orig_ros_ws` (or delete), remove all
    old-workspace source lines from `.bashrc`, `source ~/.bashrc`
    or open a fresh terminal.

--------------------------------------------------------------
42. ***YAML PARAMETER NESTING - TOP-LEVEL VS `publish:`
    SECTION***  (2026.03.14, IMU flag)
    Sergei's `bno08x_ros2_driver` reads
    `imu.use_magnetometer` from the TOP LEVEL of the params
    yaml.  If you place it under `publish.imu.use_magnetometer`,
    the driver silently ignores it and defaults to
    magnetic-north absolute yaw - which produces the "IMU axes
    reset differently on every boot indoors" symptom.
    Rule: check the driver's PARAM DECLARATIONS in its .cpp or
    .py, not the yaml the user manual happens to show.

--------------------------------------------------------------
43. ***YAML DRIVER PARAM PASSING BUG - RAW FILE INTO
    Node(parameters=...) IS NESTED, NOT FLAT***  (2025.08 GPT-5
    diagnosis)
    Passing `parameters=['/path/x.yaml']` to a `Node(...)`
    causes ROS to treat the file's KEYS as nested under
    `node_name.ros__parameters.X` instead of the flat `X` the
    driver expects.  Driver falls back to defaults silently.
    Fix EITHER: use `IncludeLaunchDescription(
    PythonLaunchDescriptionSource(driver_launch.py))` so the
    driver's own launch handles yaml properly,
    OR parse the yaml yourself:
        with open(path) as f:
            data = yaml.safe_load(f)['node_name']['ros__parameters']

--------------------------------------------------------------
44. ***ANGLE CONVENTION FOR loadgraph AND OTHER POSE ARGS***
    (2026.03.30)
    Theta is COUNTERCLOCKWISE about +Z, measured from +X (map
    East) toward +Y (map North).  Not clockwise-from-North like
    a compass.  Example poses that work:
      dock:                          0.0   0.0    0.0
      arbitrary pose facing south:  19.4  -1.05  -pi/2
      pose facing west:              X     Y     +pi

--------------------------------------------------------------
45. ***YAML `int` vs `double` IS A HARD-ERROR TYPE MISMATCH***
    Setting `1` where the driver declared `float` causes a
    parameter-load failure at node start.  Write `1.0`.  ROS
    2's type coercion is strict.

--------------------------------------------------------------
46. ***Ctrl-C-RESISTANT LAUNCH***  (recurring)
    Occasionally `ros2 launch` traps SIGINT and refuses to die.
    `htop` -> find the ros2 python launcher -> `kill -9 <pid>`.
    Cleanup rest via `pkill -9 -f articubot_one` if children
    survive.  See also item 47 (zombie cleanup drill).

================================================================
PART V - ROS 2 OPERATIONS
================================================================

--------------------------------------------------------------
47. ***THE ROS 2 ZOMBIE-PROCESS CLEANUP DRILL***  (2026.03.02)
    Symptom: `ros2 topic list` still shows topics after every
    launch is dead.  `ros2 topic info -v /cmd_vel_nav` shows
    7 publishers all called `behavior_server`.  Multiple
    `twist_mux`, `robot_state_publisher`, `teleop_twist_joy`
    processes in `ps aux`.
    Cause: previous launches left orphan child processes; the
    ros2 daemon caches the stale discovery graph.
    Fix:
      1. Kill EVERY orphan process:
           ps aux | grep -E \
             "cmd_vel|robot_state|twist_mux|teleop|nav2|slam"
           kill -9 <PID1> <PID2> ...
      2. Kill the ros2 daemon (auto-restarts):
           ps aux | grep ros2-daemon
           kill -9 <daemon-PID>
      3. Verify empty:
           ros2 node list
           ros2 topic list
    Manual: run this whenever a launch quits abnormally
    (crash, SSH drop, Ctrl-C failure).

--------------------------------------------------------------
48. ***`ros2 topic list` AUTO-RESTARTS THE DAEMON***
    (2026.03.02)
    After you kill it, the next `ros2 topic list` will spawn
    a new daemon.  It briefly re-populates from cache before
    reflecting the real graph.  Wait 2-3 seconds after the
    kill for a truly clean list.

--------------------------------------------------------------
49. ***LATCHED TOPICS REQUIRE MATCHING QoS (QUALITY OF
    SERVICE)***  (2026.06.20 - keepout mask)
    Symptom: subscribed to `/map` or `/keepout_filter_mask` in
    RViz, no data displayed even though publisher is running.
    Cause: RViz defaults to Best-Effort Reliability, but
    latched topics use Reliable + Transient-Local Durability.
    Best-Effort subscribers DISCARD the latched sample during
    the DDS (Data Distribution Service) handshake.
    Fix: in the RViz display Properties, set:
      Reliability = Reliable
      Durability  = Transient Local
    Same rule applies to any latched topic (`/map`,
    `/robot_description`, keepout filters, static map servers).

--------------------------------------------------------------
50. ***NAV2 WAYPOINT FOLLOWER SHORTCUTS BETWEEN POSES***
    (2026.03.14)
    Both `waypoint_follower` and `navigate_through_poses` invoke
    the global planner INDEPENDENTLY between waypoints.  They
    can route through obstacles or through corridors you did
    NOT intend if a "shorter" path exists.
    Workaround: place tighter waypoints (~0.3 m apart) around
    the corners you want honored.  No parameter fixes this;
    it's a Nav2 design choice.

--------------------------------------------------------------
51. ***`use_sim_time=true` ON REAL HARDWARE IS ALWAYS WRONG***
    (2025.10.21)
    Symptom: "Message Filter dropping message: frame 'X' at
    time Y for reason 'the timestamp on the message is earlier
    than all the data in the transform cache'".
    First check: grep every launch file for `use_sim_time`.
    Any node with `use_sim_time: true` on a real robot publishes
    sim-clock timestamps that don't match the wall-clock TF
    (transform) stream.  Set to false everywhere.

--------------------------------------------------------------
52. ***CROSS-HOST TIME SYNC IS NECESSARY, NOT SUFFICIENT***
    (2025.10.24 - Pito Salas's `handy net_latency` tool)
    On multi-machine ROS setups, install `chrony` or
    `systemd-timesyncd` on every host that publishes or
    subscribes to ROS 2 topics.  Utility boxes that only
    reach the robot via SSH / Foxglove / git do NOT count
    (their clock drift never enters the ROS graph).  Then
    verify skew with Pito Salas's tool
    (github.com/Boston-Robot-Hackers/handy):
        ros2 run handy net_latency node1 node2
        ros2 run handy net_latency node2 node1
    Skew under ~10 ms is fine.  Skew of 100+ ms will produce
    the same "timestamp earlier than cache" errors as sim-time
    contamination.

--------------------------------------------------------------
53. ***DDS IMPLEMENTATION MUST MATCH ACROSS ALL MACHINES***
    (2025.10.24)
    Set `RMW_IMPLEMENTATION` (RMW = ROS middleware) identically
    on every host:
        export RMW_IMPLEMENTATION=rmw_cyclonedds_cpp
    Mismatched RMWs on the same ROS_DOMAIN sometimes work by
    accident and sometimes silently drop discovery.  Ship
    everyone on cyclonedds; put the export in `.bashrc` on
    every machine.

--------------------------------------------------------------
54. ***RELIABILITY QoS OF /scan IS BEST_EFFORT ON YDLIDAR
    AND LD19***  (2025.10 recurring)
    Any subscriber that requests RELIABLE for `/scan` (RViz2
    default, some Nav2 nodes) will complain and get no data.
    Configure the subscribers to Best-Effort for LiDAR scan
    topics.

--------------------------------------------------------------
55. ***BRLTTY BLOCKS CP210x AND OTHER CH-BASED USB SERIAL
    ADAPTERS***  (Ubuntu 24.04, ~2025.04)
    Symptom: `/dev/ttyUSB0` never appears when you plug in a
    CP2102 dongle.  Cause: BRLTTY (accessibility service for
    Braille displays) claims the device on Ubuntu 24.04.
    Fix:
        sudo apt remove brltty
    You never wanted it anyway.

================================================================
PART VI - NAV2, SLAM, AMCL
================================================================

--------------------------------------------------------------
56. ***SLAM TOOLBOX ONLY CORRECTS ON LOOP CLOSURE - DRIVE
    BACK THROUGH***  (2026.04.17 - Claude Opus 4.6 lesson)
    SLAM drift silently compounds as you drive AWAY from
    known geometry.  It only snaps back when the scan matcher
    recognizes a previously-seen area.
    Workflow rule: after exploring a new far room, DRIVE BACK
    through areas you already scanned before `savegraph`.  In
    RViz2 you will literally see the map snap as loop closure
    fires; that snap is your signal to save immediately.

--------------------------------------------------------------
57. ***INFLATION RADIUS MUST BE >= CIRCUMSCRIBED RADIUS***
    (2025.08.17)
    Nav2 spits a warning if the inflation halo is smaller than
    the robot's circumscribed radius (worst-case fit-in-a-circle
    distance).  For Stormy: `inflation_radius: 0.20` combined
    with `robot_radius: 0.18` was the sweet spot in tight
    doorways; too much inflation and doorways close, too
    little and Nav2 refuses to plan.

--------------------------------------------------------------
58. ***ROBOT'S WORST-CASE DIAGONAL IS NOT THE BEST RADIUS
    FOR A DIAMOND-SHAPED ROBOT***  (2026.04.04)
    Stormy's rectangle bound is 28 x 36 cm, so worst-case radius
    is 22 cm.  But the robot is DIAMOND-shaped in plan view,
    tapering to 6 cm at the caster and 12 cm at the OAK-D nose.
    Half-length (18 cm) is a better enclosing radius, and gives
    Nav2 the ~8 cm of extra clearance it needs to pass through
    2-ft doorways.  Later replaced by a proper polygon footprint
    (item 59).

--------------------------------------------------------------
59. ***PROPER POLYGON FOOTPRINT > CIRCLE RADIUS***
    (2026.05.02)
    For non-round robots, a polygon footprint frees Nav2 to
    consider approach angle.  Stormy's 8-vertex stingray hull:
        footprint: "[[0.123, 0.06], [0.06, 0.145],
                     [-0.065, 0.145], [-0.237, 0.03],
                     [-0.237, -0.03], [-0.065, -0.145],
                     [0.06, -0.145], [0.123, -0.06]]"
    Tell Nav2's MPPI (Model Predictive Path Integral)
    controller to honor the polygon: set
    `MPPI.CostCritic.consider_footprint: true`.  DO NOT
    combine with `footprint_padding` non-zero at the same time
    (2026.05.18 - made Stormy too shy to leave dock).

--------------------------------------------------------------
60. ***NAV2 HEADING OVERSHOOT FIX - THE COMPLETE RECIPE***
    (2026.04.12)
    Symptom: Nav2 goals arrive 20-25 deg past target heading
    after MPPI approach.
    Fix requires ALL THREE:
      (a) EKF (Extended Kalman Filter) absolute yaw ON (was
          velocity-only):
            imu0_config row 2 [roll, pitch, YAW]:
              true, true, TRUE   (was false)
          EKF yaw covariance drops from ~109 rad^2 to ~0.002.
      (b) `MPPI.wz_max: 0.25` (was 0.5) - less angular
          momentum overshoots less at goal.
      (c) `MPPI.GoalAngleCritic.threshold_to_consider: 0.15`
          (was 0.5 m) - controller rotates IN PLACE at goal
          instead of during approach.
    Result: heading error 2-5 deg.

--------------------------------------------------------------
61. ***OAK-D POINT CLOUD AS NAV2 OBSTACLE SOURCE - HEIGHT
    BAND AND LOCAL/GLOBAL SPLIT***  (2026.05.02;
    persistence guidance withdrawn 2026.09.11)
    LiDAR at 15 cm misses low obstacles (coffee-table
    crossbars, shoes, pets).  Feed `/oak/points` to Nav2 as
    a PointCloud2 obstacle source, and give the LOCAL and
    GLOBAL costmaps DIFFERENT height bands.

    LOCAL costmap (fast, rolling, self-clearing):
        oak_points:
          data_type: "PointCloud2"
          topic: /oak/points
          min_obstacle_height: 0.02
          max_obstacle_height: 0.22
          marking: True
          clearing: True

    GLOBAL costmap (persistent, non-rolling):
        oak_points:
          data_type: "PointCloud2"
          topic: /oak/points
          min_obstacle_height: 0.10
          max_obstacle_height: 0.22
          marking: True
          clearing: True

    Why the split (learned 2026.07.06):
      A 0.02 m floor on the GLOBAL costmap catches OAK-D
      stereo noise on carpet, tile grout, and cable dust
      and marks it into the map.  Because the global
      costmap is not rolling AND OAK-D clearing only
      happens in the ~72 deg forward wedge, those phantom
      marks accumulate over the session, each inflated to
      a ~1 m cost mountain by the 0.50 m inflation halo.
      Result: Stormy becomes paralyzed at doorways whose
      `/map` shows clear but whose `/global_costmap` shows
      blocked.
      10 cm sits above almost all ground-noise artifacts
      while still catching a shoe, book, or pet dish (real
      hazards for a ~22 cm-tall robot).  The LOCAL costmap
      keeps 2 cm for reactive collision avoidance - its
      voxel layer and rolling window make ground noise
      self-clearing there.

    Withdrawn: earlier versions of this item recommended
    trying `observation_persistence: 1.5` before flipping
    `clearing: true`.  On Stormy the persistence path was
    never tested - the raise-the-global-floor split above
    solved the phantom-obstacle problem 2026-07-06,
    predating the persistence advice.  Persistence may
    still be worth trying on other robots whose stereo
    noise looks less like a floor-plane artifact; it is
    no longer the FIRST recommendation.

    Live-config sync:  2026-09-11 (nav2_params.yaml on
    articubot_one exploration branch @ 96c28e5, with the
    10-line inline rationale about global-costmap phantom
    accumulation).

--------------------------------------------------------------
62. ***AMCL (ADAPTIVE MONTE CARLO LOCALIZATION) vs SLAM
    MODE - PICK THE RIGHT ONE***  (2026.04.30)
    SLAM Toolbox in mapping mode:  BUILDS and updates map.
    SLAM Toolbox in localization:  BUILDS ON existing map,
                                    can add new geometry.
    AMCL + map_server:              READ-ONLY on saved map;
                                    lightest, most stable.
    Production nav on a stable map: use AMCL for lightest CPU
    and most stable behavior.  Only use SLAM localization mode
    when you expect NEW geometry to be added mid-run.

--------------------------------------------------------------
63. ***SLAM TOOLBOX PARAMS FOR PI 5 IN TIGHT SPACES***
    (2026.03.29)
    Defaults choke the scan matcher on 4-core ARM.  Reduce
    load without losing quality:
        throttle_scans:                   1 -> 3
        max_laser_range:                12.0 -> 8.0
        do_loop_closing:              false -> true
        correlation_search_space_dimension:
                                       0.75 -> 0.5
        num_threads:                     4 (explicit; Pi 5)
    When SLAM stalls, TF stops publishing, costmap fills with
    stale-timestamp scans, everything else cascades.

--------------------------------------------------------------
64. ***AMCL LOCALIZATION-LOSS RECOVERY - MORE PARTICLES,
    MORE BEAMS, TIGHTER UPDATES***  (2026.03.14)
    Tuning that stopped delocalization in a feature-poor
    open area (limited unique laser features):
        max_particles:            2000 -> 5000
        laser_max_beams:            60 -> 120
        laser_likelihood_max_dist: 2.0 -> 4.0
        alpha1..alpha4:            0.2 -> 0.1
        update_min_d:              0.1 -> 0.05
        update_min_a:              0.1 -> 0.05
    Extra CPU cost is real but worth it in featureless areas.

--------------------------------------------------------------
65. ***`allow_unknown` AND `track_unknown_space` INTERACT
    IN NON-OBVIOUS WAYS***  (2026.04.04)
    Common patterns:
      allow=true,  track=true:   planner routes THROUGH
                                 unknown space eagerly.
                                 Bad for hybrid maps.
      allow=false, track=true:   planner refuses unknown
                                 areas.  Doorways narrow to
                                 known-free pixels only.
                                 Best for mature maps.
      allow=false, track=false:  unknown treated as FREE.
                                 Planner ignores the
                                 unknown/free distinction.
                                 Only obstacles block.  Good
                                 for blueprint-based maps.

--------------------------------------------------------------
66. ***NAV2 "TIMESTAMP EARLIER THAN TRANSFORM CACHE" - THE
    FULL DIAGNOSTIC CHAIN***  (2025.10.19)
    Check in this order:
      1. Any node with `use_sim_time: true` on real hardware
         (item 51)
      2. Multi-machine time skew via Pito Salas's tool
         (item 52)
      3. DDS implementation mismatch (item 53)
      4. IMU driver hangs / quaternion-norm-zero spikes cause
         TF publishers to stall - use Sergei's smbus2 fork
         of BNO055/BNO085 driver

--------------------------------------------------------------
67. ***SLAM TOOLBOX START-DELAY IS NORMAL, NOT BROKEN***
    (Sergei 2026.01.02)
    "Localizers run with 18 s delay; Nav2 with 25 s delay.
     Wait ~40 s after launch before expecting a map or trying
     to drive."  Not a bug; a settle time.  Don't debug it -
     wait for it.

================================================================
PART VII - PERCEPTION (LIDAR, CAMERA, URDF, SIM)
================================================================

--------------------------------------------------------------
68. ***OAK-D IMU IS PUBLISHED BY THE DRIVER, DO NOT ALSO
    DECLARE IN URDF (UNIFIED ROBOT DESCRIPTION FORMAT)***
    (2025.12.14; scope note added 2026.07.26)
    `depthai_ros_driver` publishes `oak_imu_frame` as a
    STATIC TF from the camera's factory calibration EEPROM
    (translation (0, -0.015, -0.014) m relative to camera
    housing origin).  Declaring the same frame in URDF
    creates a conflicting TF and confuses RViz2.  Just don't.

    Scope note (James 2026.07.26):  On Stormy the OAK-D IMU
    was TRIED as the robot's primary IMU source; implementing
    it proved difficult and never worked, so it was
    ABANDONED.  BNO085 is authoritative
    for EKF fusion.  The advice above still applies to
    anyone who wants to enable the OAK-D IMU as an
    auxiliary source (the driver publishes the frame
    regardless), but do not read this item as an endorsement
    of the OAK-D IMU as a primary IMU choice on this
    class of robot.

--------------------------------------------------------------
69. ***`parent_frame:=<urdf_frame>` CONNECTS DEPTHAI TF TREE
    TO ROBOT***  (2025.12.14)
    In DepthAI camera launch args:
      parent_frame:=oakd_front_panel
    Then the URDF joint `oakd_joint -> oakd_front_panel`
    supplies physical position, and the driver's internal
    `oak` frames chain under it correctly.  Set
    `cam_pos_x/y/z=0.0` in the launch (URDF handles position).

--------------------------------------------------------------
70. ***GAZEBO HARMONIC (gz-sim) DOES NOT RESOLVE `package://`
    MESH URIs***  (2026.03.07)
    Symptom: mesh renders in RViz but not in Gazebo.
    RIGHT:
      <mesh filename="file://$(find articubot_one)/assets/meshes/OAK-D.dae"/>
    WRONG:
      <mesh filename="package://articubot_one/assets/meshes/OAK-D.dae"/>
    RViz2 uses ROS resource manager (handles package://); gz-sim
    doesn't.  Use file:// everywhere for cross-tool compatibility.

--------------------------------------------------------------
71. ***GAZEBO CLASSIC CAMERA PLUGIN IS SILENTLY IGNORED
    UNDER GZ HARMONIC***  (2026.03.07)
    Symptom: camera in Gazebo renders internally but publishes
    no ROS topic.  No error, just silence.
    Fix: replace the `libgazebo_ros_camera.so` plugin block
    with GZ Sim NATIVE format:
        <sensor name='oakd_rgb' type='camera'>
            <always_on>1</always_on>
            <update_rate>30</update_rate>
            <camera>
                <horizontal_fov>1.2566</horizontal_fov>
                <image><format>RGB_INT8</format></image>
            </camera>
            <topic>gz_camera</topic>
        </sensor>
    Then bridge `gz_camera -> /camera` in `gz_ros_bridge.yaml`.

--------------------------------------------------------------
72. ***RVIZ OGRE COLLADA LOADER TAKES MESH MATERIAL
    OWNERSHIP***  (2026.03.07)
    RViz2 ignores URDF `<material>` tags on `<visual>` blocks
    that use .dae meshes.  The material must be embedded in
    the DAE (Digital Asset Exchange / Collada) itself.  Add
    `<library_effects>` +
    `<library_materials>` blocks defining a phong material, and
    bind via `<bind_material>` inside `<instance_geometry>` in
    the visual scene.  Gazebo needs a separate
    `<material>Gazebo/Color</material>` inside the visual.

--------------------------------------------------------------
73. ***RVIZ MULTI-VISUAL MATERIAL BUG - ONE LINK PER
    COLOR***  (2026.06.29)
    Symptom: a single `<link>` with multiple `<visual>` blocks
    and DIFFERENT `<material>` tags renders ALL visuals with
    the FIRST material.  Per-visual material tags after the
    first are silently ignored, even with unique names and
    inline rgba.
    Fix: extract each differently-colored visual into its OWN
    `<link>` connected via a FIXED JOINT.  Fixed joints
    propagate rotation, so multi-link children of a continuous
    joint (a wheel) still spin correctly.
    Applied on Stormy: speaker (body + cone), wheels (tire +
    hub + spoke marker), E-stop (skirt + shaft + button).

--------------------------------------------------------------
74. ***LDLIDAR X-AXIS IS 90 DEG FROM WHAT YOU THINK***
    (2025.12.19)
    LDROBOT's "forward" convention is 90 deg to the right of
    what a robot builder naturally calls "front".  Rotate the
    static-TF in `ldlidar_ros2/launch/ld19.launch.py`.  For -90
    deg yaw:
        arguments=['0','0','0.18',
                   '0','0','-0.7071068','0.7071068',
                   'base_link','base_laser']
    If wrong direction, flip qz sign: '+0.7071068' for +90 deg.

--------------------------------------------------------------
75. ***LDLIDAR PHYSICAL LASER IS 0.0015 m BELOW CYLINDER
    TOP***  (2025.12.19)
    Introduce a separate `base_laser` link in the xacro
    sitting 1.5 mm BELOW the LD19 cylinder's top.  Otherwise
    the scan-plane visualization in RViz2 lands 1.5 mm too high
    and appears to float above the LiDAR body.

--------------------------------------------------------------
76. ***DEPTHAI v3 PACKAGE RENAME CASCADE***  (2026.06.15)
    On ROS Jazzy after ~2026 apt updates, all depthai package
    names got a `_v3` suffix:
      depthai_ros_driver         -> depthai_ros_driver_v3
      depthai_descriptions       -> depthai_descriptions_v3
      depthai_examples           -> depthai_examples_v3
      plugin "Camera"            -> plugin "Driver"
      config file "camera.yaml"  -> "driver.yaml"
      yaml namespace `camera.*:` -> `driver.*:`
    Apply to any pre-2026 launch or yaml.  Symptom: `[launch]
    package 'depthai_ros_driver' not found`.

================================================================
PART VIII - NETWORKING & MULTI-HOST ROS 2
================================================================

--------------------------------------------------------------
77. ***PI 5 ONBOARD 2.4 GHz WIFI IS DISABLED BY DESIGN***
    (2026.06.27, verbatim after a wasted evening)
    "The Raspberry Pi 5 has a well-documented interference
     problem on 2.4 GHz.  Might have brought that up at the
     start and saved us this rabbit hole!"
    Cause: CPU / USB3 / HDMI / PMIC noise coupling into the
    Pi's small PCB antenna.  5 GHz is largely immune; 2.4 GHz
    can't reliably complete authentication.  Symptoms:
    `wpa_supplicant status_code=16` (auth timeout) despite
    strong signal on scans; phones connect to the same AP
    with no issue.
    Fix: stay on 5 GHz for the internal radio.  If 2.4 GHz
    range is needed (through-wall), use an external USB dongle
    with its own antenna (e.g. Realtek RTL8812BU).

--------------------------------------------------------------
78. ***TP-LINK DECO MESH DROPS MULTICAST WIRED <-> WIRELESS***
    (2026.07.10, keystone)
    Symptom: `ping` between two hosts works perfectly, but
    ROS 2 `topic list` on one shows 5 topics (defaults) instead
    of the other's 135.  `Frame [map] does not exist` in RViz.
    Cause: TP-Link Deco firmware drops multicast between wired
    and wireless clients (and between mesh nodes).  DDS SPDP
    (Simple Participant Discovery Protocol) heartbeats never
    arrive.  Unicast (ping, SSH, TCP) works
    the whole time, masking root cause.
    Fix: switch CycloneDDS to UNICAST-ONLY discovery with an
    explicit peer list.  See item 79.

--------------------------------------------------------------
79. ***CYCLONEDDS UNICAST-PEER-LIST CONFIG (THE FIX)***
    (2026.07.10 - THE canonical fix for item 78)
    On BOTH hosts, save to `~/cyclonedds.xml`:
        <CycloneDDS>
          <Domain>
            <General>
              <Interfaces>
                <NetworkInterface name="<IFACE>" priority="10"/>
              </Interfaces>
              <AllowMulticast>false</AllowMulticast>
            </General>
            <Discovery>
              <ParticipantIndex>auto</ParticipantIndex>
              <Peers>
                <Peer address="<ROBOT_WIFI_IP>"/>   <!-- Stingray -->
                <Peer address="<LINUXBOX_ETH_IP>"/>   <!-- LinuxBox -->
              </Peers>
            </Discovery>
          </Domain>
        </CycloneDDS>
    Then in `.bashrc`:
        export CYCLONEDDS_URI=file://$HOME/cyclonedds.xml
    Verify: `echo $CYCLONEDDS_URI` prints the path;
    `ros2 daemon stop && ros2 daemon start; ros2 topic list | wc -l`
    now shows all topics.  Add every ROS host's IP to the
    `<Peers>` list on every host.

--------------------------------------------------------------
80. ***DUAL-HOMED HOST + DDS = SILENT INTERFACE BIND***
    (2026.07.10)
    If a machine has two IPs on the same subnet (ethernet +
    WiFi both up on the same /22), CycloneDDS silently binds
    multicast to ONE of them and the other side may never
    see the packets.  Fix: either disable the unused
    interface, OR use unicast peer list (item 79) which
    bypasses the problem entirely.

--------------------------------------------------------------
81. ***ROUTE METRIC ONLY STEERS OUTBOUND TRAFFIC***
    (2026.07.08)
    Even after you fix the default-route metric so that new
    outbound connections prefer the USB WiFi dongle over the
    Pi's onboard wlan0, INBOUND TCP connections (SSH from the
    laptop dialed to the Pi's OTHER IP, Foxglove client dialing
    the OTHER IP) still land on the interface the client
    dialed.  DDS multi-locator advertisement makes it worse.
    Real fix if one interface is definitively better: DISABLE
    the worse one:
        sudo nmcli con modify netplan-wlan0-<SSID> \
                              connection.autoconnect no
        sudo nmcli dev disconnect wlan0
    Reverse (re-enable) with:
        sudo nmcli con modify netplan-wlan0-<SSID> \
                              connection.autoconnect yes
        sudo nmcli con up netplan-wlan0-<SSID>
    (`nmcli con` and its subcommands DO require `sudo` for
    modify / up / down - only `nmcli dev wifi list` and
    similar read-only queries run as a plain user.)

--------------------------------------------------------------
82. ***FOXGLOVE STUDIO NEEDS WebSocket 8765 (foxglove_bridge),
    NOT 9090 (rosbridge)***  (2026.06.20; assets note
    corrected 2026.09.07)
    They are DIFFERENT protocols.  Foxglove's native binary
    protocol is faster and lower-latency than rosbridge JSON.
    Bridge:
        ros2 launch foxglove_bridge foxglove_bridge_launch.xml
    Studio connect string:
        ws://<robot-lan-ip>:8765

    Serving `package://` URDF meshes remotely (OPTIONAL,
    NOT verified on Stormy as of 2026.09.07):
      By default the bridge REFUSES to fetch `package://`
      assets - Foxglove Studio shows the URDF frames but
      not the mesh geometry.  To enable it, pass an
      `asset_uri_allowlist` regex list to the bridge:
          ros2 launch foxglove_bridge \
               foxglove_bridge_launch.xml \
               asset_uri_allowlist:="['^package://(?:[-\\w%]+/)*[-\\w%.]+\\.(dae|stl|urdf|xacro|mesh|obj|mtl|png|jpg|jpeg)$']"
      Or set it in a params yaml the launch file loads:
          asset_uri_allowlist:
            - "^package://(?:[-\\w%]+/)*[-\\w%.]+\\.(dae|stl|urdf|xacro|mesh|obj|mtl|png|jpg|jpeg)$"
      Then in Studio's 3D panel enable "Show URDF meshes".
      James has NOT confirmed doing this on Stormy; the note
      is retained as the documented mechanism for anyone
      who wants meshes in the remote Studio view.

--------------------------------------------------------------
83. ***`localhost` FROM WINDOWS MEANS THE WINDOWS MACHINE -
    USE LAN IP***  (2026.03.09)
    Foxglove Studio on Hank Rearden trying to reach
    `ws://localhost:8765` fails - localhost is the WINDOWS
    machine.  Use `ws://<ROBOT_WIFI_IP>:8765` (Stingray's IP).
    Get it on Linux with `hostname -I`.  Obvious in retrospect,
    burned an evening.

--------------------------------------------------------------
84. ***SSH KEEPALIVE TRIPLE FOR VSCODE REMOTE-SSH
    RELIABILITY***  (2026.06.01; verified 2026.07.20)
    All three files must agree.
    Windows client `%USERPROFILE%\.ssh\config` (canonical
    wildcard form - applies to every host):
        Host *
          AddressFamily inet
          ServerAliveInterval 30
          ServerAliveCountMax 6
          TCPKeepAlive yes
        Host Stingray
          HostName <ROBOT_WIFI_IP>      # wlxUSB dongle IP
          User ubuntu
          AddressFamily inet
        Host LinuxBox
          HostName LinuxBox
          User ubuntu
    (Per-host `ServerAliveInterval` also works - just repeat
    inside each `Host` block instead of `Host *`.)
    VS Code Windows-side `settings.json`:
        "remote.SSH.connectTimeout": 60,
        "remote.SSH.serverInstallTimeout": 300,
        "remote.SSH.lockfilesInTmp": true,
        "remote.SSH.useLocalServer": true,
        "remote.SSH.maxReconnectionAttempts": 5
    Server-side `/etc/ssh/sshd_config` (append):
        TCPKeepAlive yes
        ClientAliveInterval 30
        ClientAliveCountMax 10
    Then `sudo systemctl restart ssh`.
    Note: the `remote.SSH.*` settings live in the WINDOWS
    (client) settings.json, not the Pi's.  Common mistake.

================================================================
PART IX - BACKUP AND REBUILD DISCIPLINE
================================================================

--------------------------------------------------------------
85. ***FULL-DISK `dd | gzip` BEATS `rsync` FOR BASE OS
    BACKUP***  (2025.11.23)
    Reserve `rsync` for INCREMENTAL, non-system, source-tree
    backups.  For the base OS install, use:
        sudo sh -c 'dd if=/dev/nvme0n1p2 bs=4M \
                        conv=sync,noerror status=progress \
                    | gzip -1 \
                    > /media/.../nvme_root.img.gz'
        # ALSO the boot partition:
        sudo sh -c 'dd if=/dev/nvme0n1p1 bs=4M ...'
        # Verify:
        gzip -t nvme_root.img.gz && echo OK
    Restore:
        gunzip -c nvme_root.img.gz \
            | sudo dd of=/dev/nvme0n1p2 bs=4M status=progress

--------------------------------------------------------------
86. ***USB BACKUP DRIVE MUST BE ON A POWERED HUB FOR LONG
    dd RUNS***  (2025.11.23)
    Bus-powered USB HDDs disconnect partway through a 30-60
    minute dd operation.  Symptom: drive vanishes from `lsblk`
    mid-copy, `dmesg` shows `usb ... device not accepting
    address ..., error -71`.  Cause: hub or Pi USB power
    insufficient for sustained draw + spin-up transients.
    Fix: powered USB hub or direct blue USB3 port on the Pi 5.

--------------------------------------------------------------
87. ***USB DRIVE FILE-SYSTEM CHOICE - exFAT, NOT FAT32***
    (2025.11.23)
    FAT32 has a 4 GB single-file limit; a full NVMe image
    truncates.  exFAT supports arbitrarily large files and
    is readable on Linux + Windows + Mac.
    One-time setup (all data on drive lost):
        sudo parted /dev/sda mklabel gpt
        sudo parted /dev/sda mkpart primary 0% 100%
        sudo partprobe /dev/sda
        sudo apt install exfatprogs
        sudo mkfs.exfat /dev/sda1

--------------------------------------------------------------
88. ***COMMIT + PUSH EVERYTHING DAILY. IF IT'S NOT ON GITHUB,
    IT DOESN'T EXIST***  (2026.06.04 - the disaster's headline
    lesson; corollary added 2026.07.26)
    The rsync catastrophe wiped Stormy's SSD.  What survived
    was on GitHub (articubot_one main + exploration,
    roboclaw_driver fork).  What was lost was everything not
    yet pushed: memory files, tasks.json, indicators config
    not committed, rosbags, unpushed scripts.
    Rule: end of every substantive session, `git add -A && git
    commit -m ... && git push`.  Especially for config-only
    edits that "aren't code".

    Corollary - keep LOCAL edits out of upstream PRs.
    Two goals in tension:
      (i)  EVERY config file should be on GitHub as disaster
           insurance (else the previous rule fails).
      (ii) Local parameters (IPs, house-specific poses,
           personal PID tunes) should NOT propagate upstream
           in shared PRs.
    Reconciliation:  practicalities depend on the specific
    repo (private fork vs shared upstream) and on which files
    carry local values.  Standard mechanisms include private
    forks, protected branches, .gitignore + templates, git
    skip-worktree, and separate dotfiles repos (see item 89).
    Pick the mechanism at push time on a per-file basis.  Do
    not let the ambiguity become an excuse to leave anything
    uncommitted.

--------------------------------------------------------------
89. ***DOTFILES REPO FOR CONFIG FILES***  (2026.06.29;
    categorization expanded 2026.07.26)
    A private GitHub repo (github.com/JHPHELAN/stingray-
    dotfiles) holds MACHINE- AND USER-SCOPED config that is
    NOT project-source.  Concrete contents on Stormy:
        Shell / editor / git:
          ~/.bash_aliases, ~/.bashrc, ~/.inputrc, ~/.gitconfig
        Access:
          ~/.ssh/authorized_keys
        System-level (udev):
          /etc/udev/rules.d/99-robot.rules
          /etc/udev/rules.d/80-movidius.rules
        ROS runtime:
          ~/cyclonedds.xml

    Which config lives WHERE (rule of thumb):
      DOTFILES repo (stingray-dotfiles, PRIVATE):
        Anything scoped to "this machine" or "this user":
        shell environment, SSH keys, udev rules, network
        interface names, DDS peer lists, tasks.json,
        editor preferences.
      SOFTWARE repo (articubot_one/jp):
        Anything a Manual-follower needs to reproduce the
        robot: URDF, launch files, node source, package
        yamls that ship as reasonable defaults.
      BUILD repo (stingray, PUBLIC):
        Hardware descriptors: BOM, photos, mechanical
        drawings, chassis details.
      Files that have BOTH shipping-default and per-house
      local values (map yamls, IP addresses, PID tunes)
      are the awkward middle case - see item 88's corollary
      for the mechanisms and defer the per-file decision
      to push time.

    With `sync-from-live.sh` and `sync-to-live.sh` (--apply for
    write, else dry-run).  Post-disaster restore = clone this
    repo + `sync-to-live.sh --apply`.  Do this EARLY.

--------------------------------------------------------------
90. ***"BACKUP BEFORE ANY HARDWARE PIVOT" RULE***
    (2025.11.23)
    Before swapping IMU, replacing LiDAR, changing power topology,
    or any other invasive change - image the SD/SSD first.
    Compressed image of a fresh Ubuntu robot install is ~13 GB
    and takes ~40 min at 115 MB/s.  Trivial insurance premium.

--------------------------------------------------------------
91. ***`stingray-dotfiles` REPO IS THE POST-DISASTER FIRST-
    RESTORE STEP***  (2026.06.29 doctrine)
    After a fresh OS install + `ros-jazzy-desktop`, the FIRST
    action is:
        git clone https://github.com/JHPHELAN/stingray-dotfiles
        cd stingray-dotfiles
        ./sync-to-live.sh --apply
    That restores bash aliases, tasks.json, cyclonedds.xml, udev
    rules, .inputrc, .ssh - the muscle-memory environment - in
    30 seconds.  Then clone repos + colcon build.

--------------------------------------------------------------
92. ***KILL-SWITCH SPARE ON THE SHELF***  (2026.05.04)
    Remote key-fob kill-switch died silently on Stormy with no
    LED indication of "SHOULD light on power-up" (docs
    inadequate).  Ordered two replacements just in case.
    Same rule for any single-point safety device.

================================================================
PART X - TOOLS, ECOSYSTEM, PEOPLE
================================================================

--------------------------------------------------------------
93. ***WIMBLE'S `roboclaw_driver` > BASICMICRO's
    `basicmicro_ros2`***  (2026.03.28 shootout)
    For a differential-drive robot on Pi 5:
      Wimble    3700 lines C++, direct POSIX termios, no ext
                deps, hand-written, battle-tested on Sigyn,
                hardware-enforced distance-limited watchdog.
      BasicMicro 10000 lines Python + 18300 lines mock-based
                tests, external Basicmicro_python library
                loaded via sys.path.insert hack, AI-generated
                per its own header, over-engineered for
                trajectories + servos + homing you don't need.
    Wimble wins on:  deployment simplicity (colcon build only),
                     performance (no GIL, no library overhead),
                     safety model (hardware watchdog),
                     auditability (~afternoon to read all).
    Cite in the Manual current-hardware chapter so future
    maintainers don't "helpfully" switch back.

--------------------------------------------------------------
94. ***`ros2-copilot-skills` MATERIALLY IMPROVES AI OUTPUT***
    (2026.04.23 - Michael Wimble published, 158 SKILL.md files)
    Install once, benefit forever:
        git clone https://github.com/wimblerobotics/ros2-copilot-skills.git \
                  ~/.copilot/skills
    VS Code + Copilot auto-consults relevant skills before
    answering ANY prompt in ANY workspace.  Zero token overhead
    for unrelated queries (description-only discovery).  Skills
    with immediate Stormy relevance:
        mppi-critics, amcl-tuning, ekf-sensor-fusion,
        costmap-architecture, inflation-layer, slam-toolbox
    Update:  `cd ~/.copilot/skills && git pull`.

--------------------------------------------------------------
95. ***SERGEI GRICHINE'S FORKS ARE THE DEFAULT
    PICKS***  (recurring; list trimmed 2026.07.26)
    On Stormy the canonical drivers/packages sourced from
    slgrobotics are:
      slgrobotics/bno08x_ros2_driver
          - smbus2-based (fewer I2C stalls than flynneva/bno055
            which uses older smbus lib)
          - use_magnetometer YAML key is TOP-LEVEL (item 42)
      slgrobotics/bno055 (fork of flynneva)
          - transitional; retired when BNO085 arrived
      slgrobotics/articubot_one wiki
          - the canonical workspace layout Stormy adopts
          - source of the `stingray/` robot folder pattern
      slgrobotics/wifi_logger_visualizer (heat map)
    Also available from slgrobotics but NOT deployed on
    Stormy (documented here so a follower on a differently-
    shaped robot can find them):
      slgrobotics/depthai_rospi   - OAK-D LITE bringup
                                    (Stormy uses the regular
                                    OAK-D via ros-jazzy-
                                    depthai-ros-v3 apt
                                    package, not this fork)
      slgrobotics/ros_battery_monitoring  - not deployed
      slgrobotics/scan_to_range           - not deployed
    Add Sergei Grichine to the collaborators list.

--------------------------------------------------------------
96. ***WIMBLE'S `roboclaw_studio` REPLACES BASICMICRO
    MOTION STUDIO ON LINUX***  (2026.03.17)
    Motion Studio is Windows-only and refuses to set LBmin
    (logic-battery minimum) below 5.5 V on the 2x7A V5c.
    `roboclaw_studio` is a Python
    PyQt6 tool that talks to the RoboClaw via serial, can send
    the SETMINLB / SETMAXLB opcodes (commands 26, 27) or the
    newer SETLOGICVOLTAGES (command 58) - see item 97.
        git clone https://github.com/wimblerobotics/roboclaw_studio
    Install prerequisites in a Python venv (Ubuntu 24.04 refuses
    system pip); one-time `sudo apt install libxcb-cursor0`
    fixes the Qt xcb plugin error.

--------------------------------------------------------------
97. ***ROBOCLAW 2x7A V5c HAS NO EXTERNAL LOGIC BATTERY -
    SUPPRESS THE FALSE 3-RED-BLINK***  (2026.03.23)
    The 2x7A generates its own ~3.3 V logic rail internally.
    Factory default has Min LB = Max LB = 5.5 V; actual 3.3 V
    trips status bit 0x00000010 (mapped ERROR_LBATHIGH),
    3-red-blink LED.  Motion Studio LOCKS the min at 5.5 V
    and refuses lower.
    Fix (RAM-only, applied on every driver startup by James's
    fork of roboclaw_driver):
        Send Command 58 SETLOGICVOLTAGES with min=0 (0.0V)
        max=140 (14.0V).  Wide window; defensive against
        regulator variation.  See
        `roboclaw_cmd_set_logic_battery_voltages.h` in
        JHPHELAN/roboclaw_driver@main.

--------------------------------------------------------------
98. ***PITO SALAS'S `handy net_latency` FOR MULTI-MACHINE
    DDS TIMING***  (2025.10.24)
    Repo: github.com/Boston-Robot-Hackers/handy.  Two nodes
    exchange wall-clock stamps; receiver computes skew.
    Cite item 52 for usage.  Small tool, invaluable when
    two-machine ROS produces mysterious TF cache errors.

--------------------------------------------------------------
99. ***FLUX.AI IS "ARTIFICIAL STUPIDITY" FOR PCB LAYOUT***
    (2026.05.16, verbatim)
    "Flux.ai isn't AI, it's AS - Artificial Stupidity!  It was
     neurotically obsessive and indecisive!"
    $20 Pro tier ate all ACUs halfway through the second
    project.  Use KiCAD; hand-lay schematic + PCB; order from
    JLCPCB (~$55 including shipping + duties + tax for Stormy's
    indicators board).  For circuit-design AI assistance, use
    Claude Opus in ASCII schematic mode - it produces workable
    circuits with component values and knows about
    logic-level-vs-standard MOSFET thresholds.

--------------------------------------------------------------
100. ***USE LOGIC-LEVEL MOSFETS (IRLZ44N) FOR 3.3V GPIO
     DIRECT-DRIVE***  (2026.05.29 - Rev 3 PCB)
     IRFZ44N has Vgs(th) ~2-4 V and doesn't fully enhance
     until Vgs = 10 V - driving it from Pi 3.3 V GPIO leaves
     it in the linear region, hot and dim.  Options:
       (a) IRLZ44N (logic-level, pin-compatible drop-in).
           Fully on at Vgs = 3.3 V.  CORRECT choice.
       (b) NPN 2N3904 level-shifter from GPIO to a 12 V pull-up
           on the IRFZ44N gate.  Works but inverts polarity
           and adds a transistor.
       (c) Dedicated gate driver IC.  Overkill for a
           single-bulb load.
     Stormy's Rev 3 indicators PCB uses two IRLZ44N direct
     from GPIO 17 (headlights) and GPIO 27 (LED strobe).

--------------------------------------------------------------
101. ***PREFER USB AUDIO + WAV OVER PIEZO BUZZER***
     (2026.05.15)
     Piezo buzzers have exactly one tone.  A USB-C audio DAC
     dongle + tiny 8 ohm speaker (Amazon B00IRVQ0F8 +
     B0B4D1BN4F) can play any WAV, giving state-aware audio:
     "beacon on / Nav2 abort / Danger Will Robinson / boot
     chime".  Playback via `aplay` subprocess spawn is
     non-blocking; guard with a flag to prevent overlap; drive
     from indicators_node.py.  MP3 -> WAV conversion:
         ffmpeg -i input.mp3 -ar 44100 -ac 2 \
                -sample_fmt s16 output.wav
     Boost volume (safe, peak-normalize):
         sox in.wav out_LOUD.wav norm -0.1 gain 6

--------------------------------------------------------------
102. ***RESERVE THE OFFICIAL POWERWERKS CRIMPER FOR
     POWERPOLE***  (2026.01.11)  See item 29.

--------------------------------------------------------------
103. ***SERGEI'S BNO085 TIPS WIKI - USE IT AS THE IMU
     COMMISSIONING CHECKLIST***  (2026.02.10)
     Reference:
       https://github.com/slgrobotics/articubot_one/wiki/
       IMUs-%E2%80%90-Tips-and-Lessons
     Sanity-check axes with the accelerometer / gyro table.
     For a mag-enabled BNO085 (Stormy's is 6-DOF, so this
     table does not apply to Stormy - see item 32 canonical
     mag-disable note), look up the local magnetic field
     with NOAA's calculator, using WMMHR-2025 (World
     Magnetic Model High Resolution) as the model:
       https://www.ngdc.noaa.gov/geomag/calculators/magcalc.shtml
     Enter your latitude and longitude; the calculator
     returns:
       Declination     (deg, angle between mag and true North)
       Inclination     (deg, magnetic dip angle from horizontal)
       Total intensity (nT or uT)
       X (North), Y (East), Z (Down) components (nT)
     Use those values as expected magnitudes for calibration
     checks against `/imu/mag`.  For Stormy's latitude
     (approximately 30 N, 95 W - central US Gulf Coast),
     total intensity is roughly 46 uT and inclination is
     roughly 59 deg, but only your specific location's
     values are meaningful.

--------------------------------------------------------------
104. ***MOUNT EXFAT ON UBUNTU 24.04 WITHOUT THE -t FLAG***
     (2026.07.31 - first Tier-2 backup to the Sabrent HDD)
     Symptom:  `sudo mount -t exfat /dev/sda1 /mnt/backup`
     fails with "wrong fs type, bad option, bad superblock,
     missing codepage or helper program, or other error"
     even though `blkid` cleanly reports the partition as
     TYPE="exfat" with a valid UUID.
     Cause:  `-t exfat` invokes the userspace `mount.exfat`
     helper from the `exfat-fuse` package, which is NOT
     installed by default on Ubuntu 24.04.
     Fix:  drop the `-t` flag entirely.  The kernel `exfat`
     module (in-tree since Linux 5.4, autoloaded on Ubuntu
     24.04) handles the mount via /proc/filesystems
     auto-detection:
         sudo modprobe exfat        # if not already loaded
         sudo mount /dev/sda1 /mnt/backup
     Verify:  `mount | grep sda1` should print `type exfat`
     (kernel driver), NOT `type fuseblk` (userspace helper).
     Alternative if you insist on `-t exfat`:
         sudo apt install exfat-fuse
     Encountered during the first Chapter 20.4 weekly backup
     of Stormy's 238 GB root partition to the Sabrent USB
     adapter + Seagate ST3160812AS 160 GB.  Backup completed
     at 114 MB/s over USB 3.0 (blue port); 13 GB compressed
     image, verified with `gzip -t`.

--------------------------------------------------------------
105. ***SILENCE FOXGLOVE_BRIDGE PARAMETER-PROBE WARNINGS
     WITH `--log-level rclcpp:=error`***  (2026.08.30)
     Symptom:  running foxglove_bridge alongside Nav2 +
     robot_localization produces steady periodic spam in
     the ekf_node and nav2 container logs:
         [rclcpp] Failed to get parameters: parameter
                  'imu1' is not initialized
         [rclcpp] Failed to get parameters: parameter
                  'FootprintApproach.points' is not initialized
     Two paired offenders, roughly every 15 s each.
     Cause:  foxglove_bridge polls every declared parameter
     name on every reachable node every ~15 s (so the Studio
     panel can offer them for editing).  When it queries a
     name that IS declared elsewhere but is NOT declared on
     the specific node being polled, rclcpp's client library
     emits the warning.  Two names show up naturally on
     Stormy:
       - `imu1` on ekf_node - EKF's config uses imu0 only,
         but the parameter namespace advertises imu1 as an
         accepted slot.
       - `FootprintApproach.points` on collision_monitor -
         undeclared on purpose because the plugin subscribes
         to `/local_costmap/published_footprint` dynamically.
     Both are cosmetic - the graph is healthy, EKF is fusing,
     collision_monitor is watching.  Neither affects
     behavior.
     Fix:  set `--log-level rclcpp:=error` on the CONTAINING
     process arguments to hush only the rclcpp client-library
     logger.  Named-node loggers (collision_monitor, ekf,
     controller / planner / behavior servers, TF, DDS) still
     log at their normal levels.
       In ekf_imu_odom.launch.py (the ekf Node action):
           Node(
             ...
             parameters=[ekf_params_file, ...],
             remappings=[("odometry/filtered", "odometry/local")],
             arguments=["--ros-args", "--log-level",
                        "rclcpp:=error"],
           )
       In navigation.launch.py (the nav2 composable-node
       container - covers every composable node loaded into
       it):
           ComposableNodeContainer(
             name='nav2_container',
             parameters=[nav2_params_file],
             output='screen',
             arguments=['--ros-args', '--log-level',
                        'rclcpp:=error'],
           )
     General pattern:  when a downstream introspection tool
     (foxglove_bridge, plotjuggler-remote, custom dashboards)
     turns rclcpp `get_parameters` misses into log noise,
     silence rclcpp SPECIFICALLY - not the whole node - on
     the offending process.  Do NOT reach for
     `--log-level fatal` on the whole container; that hides
     real Nav2 / TF errors along with the noise.

--------------------------------------------------------------
106. ***SABRENT USB HDD ON PI 5 NEEDS `usb-storage.quirks`
     TO SURVIVE HEAVY READS***  (2026.09.13)
     Symptom:  a fresh weekly Section A backup writes both
     images cleanly at 105 MB/s and `gzip -t` passes right
     after `dd`, BUT a subsequent heavy read (e.g. `scp
     nvme_root_*.img.gz hankrearden:...` for Tier 4a) dies
     seconds in with:
         scp: read local ".../nvme_boot_*.img.gz":
              Input/output error
     Dmesg shows the smoking gun:
         scsi host0: uas_pre_reset: timed out
         sd 0:0:0:0: [sda] tag#N FAILED Result:
             hostbyte=DID_NO_CONNECT
         I/O error, dev sda, sector <big number>
         usb 3-1: reset SuperSpeed USB device
         scsi 1:0:0:0: Direct-Access  SABRENT  4102
     The device re-enumerates as /dev/sdb (or bounces back
     and forth between sda/sdb).  Every heavy read attempt
     repeats the reset.
     Cause:  the Sabrent USB 3.0 enclosure uses a JMicron
     bridge (VID:PID 152d:a578).  This chipset is a known
     UAS (USB Attached SCSI) offender - it advertises UAS
     support but botches queue management under sustained
     read load on Pi 5's xHCI, hitting a driver timeout
     that force-resets the whole USB device.  Writes are
     less affected because there is more idle time between
     dd blocks; reads by scp pump the pipeline flat-out.
     Fix:  force the enclosure to use the older BOT
     (Bulk-Only Transport) mode via a kernel cmdline quirk.
       1. Add `usb-storage.quirks=152d:a578:u` to the
          FRONT of /boot/firmware/cmdline.txt (single line;
          preserve everything after it).  Back up first:
            sudo cp /boot/firmware/cmdline.txt \
                    /boot/firmware/cmdline.txt.bak.$(date +%F)
            sudo sed -i \
                '1s|^|usb-storage.quirks=152d:a578:u |' \
                /boot/firmware/cmdline.txt
       2. Reboot.
       3. Verify with `lsusb -t` - the Sabrent entry now
          shows `Driver=usb-storage` at 5000M instead of
          `Driver=uas`.  `cat /proc/cmdline` should include
          the quirk.
     After the reboot, `scp /mnt/backup/nvme_root_*.img.gz
     hankrearden:iCloudDrive/Stormy/` completes cleanly at
     ~50 MB/s over SSH-encrypted gigabit ethernet with no
     UAS timeouts.
     Look up your own enclosure's VID:PID with
     `lsusb | grep -i <label>`; the `u` flag means "disable
     UAS" (there are others - see `Documentation/admin-
     guide/kernel-parameters.txt` in the Linux tree for the
     full quirk-letter table).
     Discovered while wiring up the automated `diskbackup
     --icloud` Tier 4a workflow: the fresh dd|gzip write
     of today's image had succeeded 40 min earlier and
     verified clean, but the moment scp started reading it
     back the drive bus-reset.  Post-quirk retry succeeded
     first try.
     Companion issue for the same enclosure at first
     mount:  item 104 (drop `-t exfat`, kernel driver does
     the right thing).

--------------------------------------------------------------
107. ***PROBE HANK REARDEN WITH `"exit 0"`, NOT `true`***
     (2026.09.13 - same evening as items 106 and the first
     `diskbackup --icloud-only` end-to-end test)
     Symptom:  passwordless SSH from Stormy to Hank Rearden
     is fully working - direct `ssh hankrearden echo OK`
     prints OK - but every `rescue` and `diskbackup --icloud`
     invocation still ended in the graceful WARN branch:
         WARN: hankrearden not reachable via passwordless SSH.
     Then a manual retry of the same scp command succeeded
     immediately.  Twice in one session, before the pattern
     was noticed.
     Cause:  the reachability probe at the top of the two
     scripts was:
         if ssh -o BatchMode=yes -o ConnectTimeout=5 \
                hankrearden true 2>/dev/null; then
     `true` is a Unix builtin.  Hank Rearden is Windows.
     The OpenSSH server on Windows invokes cmd.exe (or
     PowerShell), which reports:
         'true' is not recognized as an internal or external
         command, operable program or batch file.
     The command exits nonzero, ssh's exit code follows,
     the probe reports "unreachable" even though the SSH
     transport succeeded in ~300 ms.
     Fix:  use `"exit 0"` - a shell builtin on cmd.exe,
     PowerShell, AND every POSIX shell - so the probe means
     what it says regardless of the remote shell:
         if ssh -o BatchMode=yes -o ConnectTimeout=5 \
                hankrearden "exit 0" 2>/dev/null; then
     Applied to both tools/backup_disk.sh and
     tools/bundle_rescue_kit.sh in the same commit.
     General rule for probes across a mixed-OS SSH link:
       - `"exit 0"` - portable
       - `hostname` - portable (cmd.exe and Unix)
       - `echo ok` - portable
       - `true`, `:` - Unix only.  DO NOT use.
       - `ver` - Windows only.  DO NOT use.
     Discovery cost:  ~15 min of debugging.  Would have
     been ~0 if the probe had been sanity-checked against
     the actual remote shell before it shipped.

--------------------------------------------------------------
108. ***LINUX AUTOMOUNT + WRITE CACHE != WINDOWS QUICK
     REMOVAL***  (2026.09.14)
     Windows offers a "Quick removal" policy (default since
     Windows 10) that lets you yank a USB drive without
     using "Safely Remove Hardware".  Under the hood it
     disables the write-back cache on the device, so every
     write goes to hardware before returning.  Slower, but
     safe against sudden unplug.
     Linux does NOT have an equivalent one-checkbox toggle.
     The kernel aggressively caches writes in RAM for
     throughput (which is why STORMYBAK images at 105 MB/s;
     with `mount -o sync` the same run would crawl at
     ~20 MB/s).  Yanking a Linux-mounted exFAT filesystem
     mid-write corrupts it.  Always unmount first.
     The closest equivalent to Quick Removal semantics is
     the fstab combination `x-systemd.automount` +
     `x-systemd.idle-timeout=Nmin`:
       - mount is created lazily on first access to the
         mountpoint (no manual `mount` command),
       - and automatically torn down after N minutes of no
         I/O.
     Full fstab line used on Stormy:
         LABEL=STORMYBAK  /mnt/backup  exfat  \
           defaults,noatime,uid=1000,gid=1000, \
           x-systemd.automount, \
           x-systemd.idle-timeout=5min, \
           nofail  0  0
     After adding, `sudo systemctl daemon-reload` and
     `sudo systemctl start mnt-backup.automount`.  From then
     on:  plug in the drive, run `diskbackup`, unplug when
     it says Done.  The script's explicit umount step still
     runs at the end (belt-and-braces); the idle-timeout is
     a safety net if the script fails midway or the user
     forgets to run it after plugging in.
     Gotcha:  `mountpoint -q /mnt/backup` returns YES even
     before any access, because the autofs "waiting" mount
     satisfies the check.  Scripts that want to verify the
     REAL exfat mount must use `findmnt -q -t exfat
     /mnt/backup` after touching the mountpoint (a bare `ls`
     is enough to trigger automount).  Updated
     tools/backup_disk.sh's sanity check accordingly.
     Cross-reference:  item 104 (drop `-t exfat` for the
     kernel driver on Ubuntu 24.04); item 106 (JMicron UAS
     quirk for the Sabrent enclosure).  Both are
     prerequisites for this fstab line to "just work".

================================================================
INDEX BY SYMPTOM (quick-lookup when something goes wrong)
================================================================

Symptom                                            Items to check
---------------------------------------------------------------------
"Message Filter dropping message: frame ...
    timestamp earlier than transform cache"        51, 52, 53, 66
Wheel does honey-bee-dance, one motor jiggles      17, 21
Motor cooks silently                              21, 26
Encoder reads ~half of counts-per-revolution (CPR)  17
RoboClaw 3-red-blink at rest                       97
Motors don't respond to joystick                   36, 37
Nav2 goal heading overshoot                        60
Robot too shy to leave dock                        58, 59, 65
SLAM drift accumulates on far-room trip            56
AMCL delocalizes in featureless area               64
Doorway pinch prevents planning                    57, 58, 59
IMU orientation resets differently every boot      42
IMU stalls at imu_received_flag_ = 0x02 (accel only) 32
Pi 5 low-voltage warning at splash / reboots       19, 24
Bench PSU voltage sags with buck converter         16
Motor melts / drive shaft won't turn               26
Encoder value stuck near ~half-CPR                 17
Camera renders in Gazebo but no ROS topic          71
Mesh missing in Gazebo but in RViz                 70
Mesh wrong color / white in RViz                   72, 73
LiDAR points 90 deg off from expected              74
`ros2 topic list` returns 5 topics on second host  47, 78, 79
Pi 5 can't associate with 2.4 GHz WiFi             77
Foxglove Studio connection failed                  82, 83
foxglove_bridge log spam - "not initialized"       105
Sabrent USB HDD: scp/gzip -t "Input/output error",
    dmesg "uas_pre_reset: timed out"                106
`rescue` or `diskbackup --icloud` prints
    "hankrearden not reachable" but manual scp works  107
"Do I need to unmount before unplugging?" (yes; Linux
    does not have Windows Quick Removal semantics)      108
Global costmap paralysis at doorways               61
RViz keepout mask / map missing                    49
Config edit didn't take effect                     40
Driver won't compile after apt update              38, 76
YAML parse error "Sequences cannot be key"         35
Boot fails after AI-suggested kernel install       7
`sudo mount -t exfat` fails "can't read superblock" 104

================================================================
INDEX BY STARDATE (chronological reference to source log)
================================================================
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

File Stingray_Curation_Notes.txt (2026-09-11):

STINGRAY EXPERIENCE - CURATION WORKING NOTES
Started: 2026.07.20
Source: Stingray Experience.txt (44,832 lines, 235 stardates, 2023.05.06 - 2026.07.11)
Method: chronological pass, chunk by chunk. Each entry tagged:
  M = keep for Builder's Manual (current-state fact, working config, verified procedure)
  F = keep for Field Notes (lesson, symptom-to-cause, principle, "don't do this again")
  N = keep for Narrative / backstory color (verbatim or lightly edited - the
      human story that gives the project a soul; goes into a "How Stormy
      came to be" chapter in the Manual, not into the tech chapters)
  C = cut (day-of noise, dead exploration with no takeaway, shipping details, stale links)
  ? = flag for James: contradiction or unresolved

================================================================
CHUNK 1  lines 1 to ~1100  spans 2023.05.06 through 2025.01.12
================================================================

2023.05.06  (L1)  Project mission statement
  M  Origin condensed: Parallax Stingray 2010 body + Articulated Robotics
     tutorials.  Metal plates replaced with laser-cut 1/8" and 3/8" acrylic
     (custom mounts, interior visible).  Propeller board replaced by
     Raspberry Pi 5.  Top: LIDAR, LiPo cell, low-voltage shutoff.  Front:
     fisheye or depth camera (OAK-D or RealSense), 3 headlights.  Back:
     voltage regulator, 12V power bus.  Interior: Pi 5, RoboClaw 2x7A,
     powered USB hub.
     >>> NOTE:  the 12V bus, buck converter, and USB hub have all since
     been superseded by the 52Pi PD power expansion board (per Handoff
     Note.txt).  Manual should carry the intent (power distribution +
     compute + drive + sensing) but the specifics need refresh from
     Stormy Essentials.
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

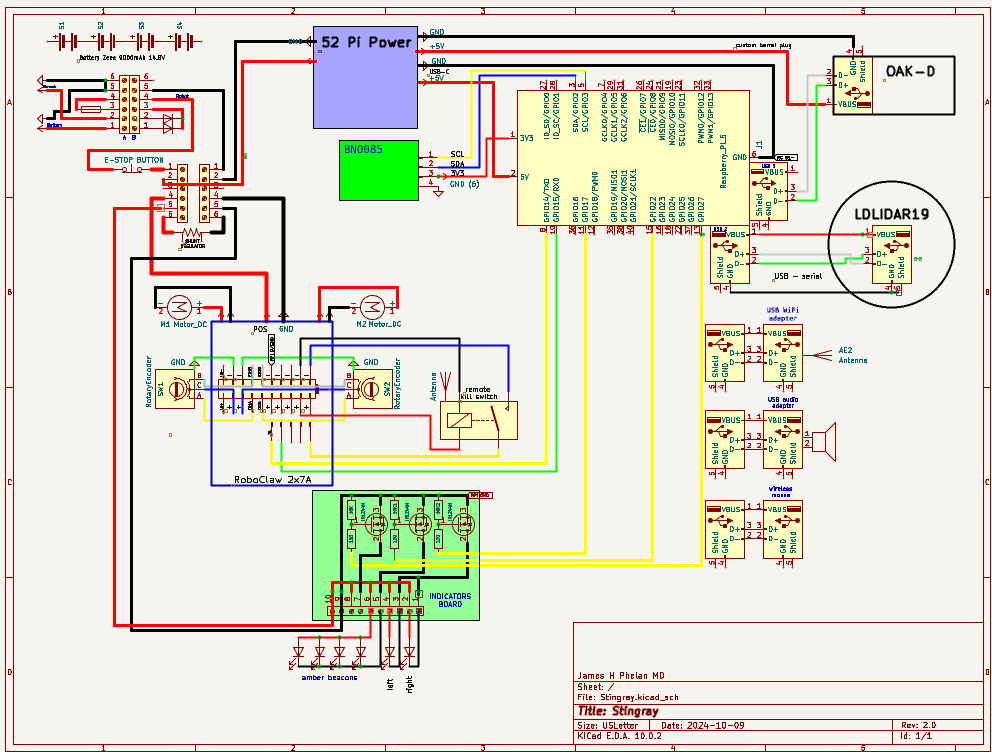
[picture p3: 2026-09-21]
images/Stormy Schematic 2026.09.20.png

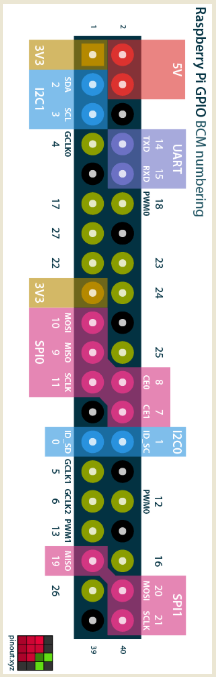
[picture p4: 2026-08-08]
images/Raspberry Pi GPIO pinout.png

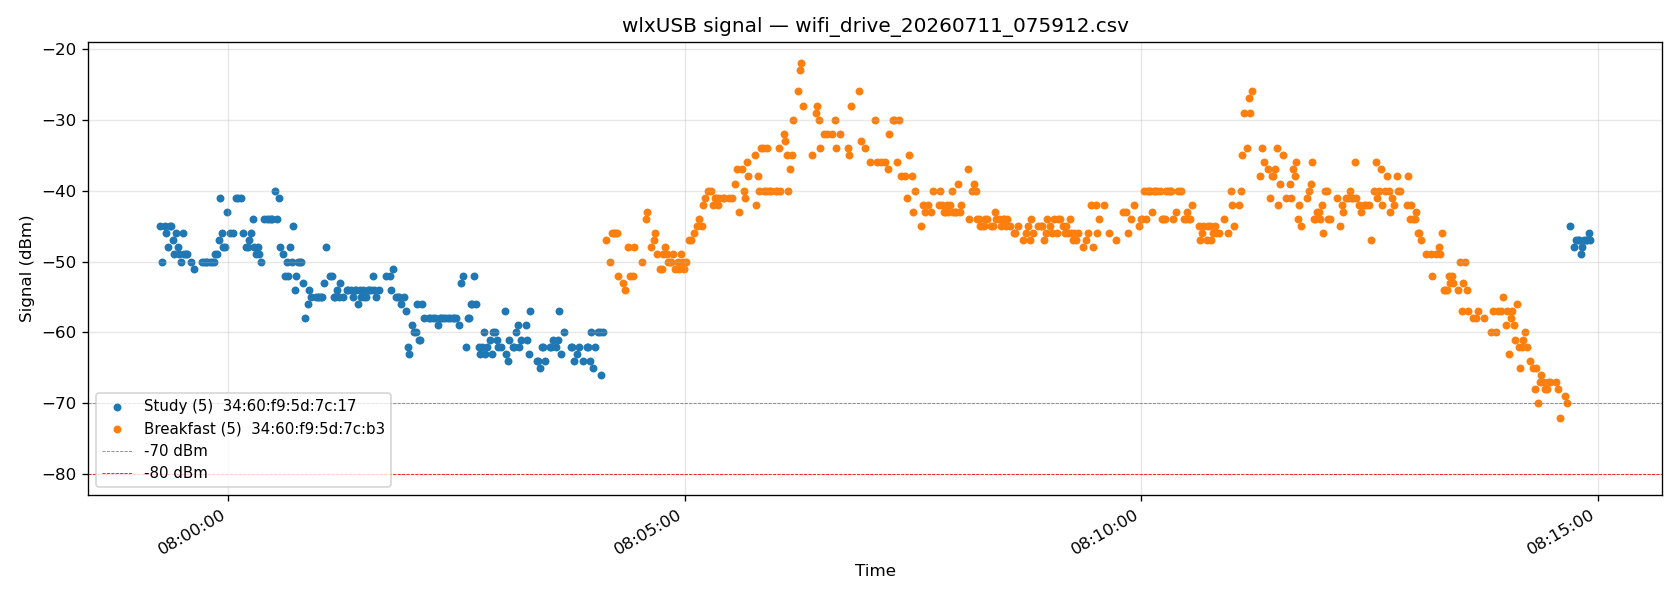
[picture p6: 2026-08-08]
images/wifi_drive_20260711_075912_signal.png

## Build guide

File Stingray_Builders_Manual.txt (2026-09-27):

================================================================
STORMY THE STINGRAY - BUILDER'S MANUAL
Version 1.2 - Compiled 2026-07-20; public release 2026-09-11;
              amended 2026-09-21 (right rear Power Input Panel
              hardware caught up: Ch 3.1 rewritten, FN 22 gains
              DMM verification sub-section and 15SQ045 part
              swap, Appendix G.9 schematic bumped to 2026.09.20);
              amended 2026-09-27 (Panel hot-swap verified; green
              power-source indicator LED added to bench input
              side; Ch 3.1 and FN 22 gain LED sub-sections;
              Panel photo filenames updated to current)
================================================================

Owner:       James H Phelan, MD
Location:    Humble, TX
Repos:       Build descriptor (primary):
               https://github.com/JHPHELAN/stingray
             Software (this Manual's code references):
               https://github.com/JHPHELAN/articubot_one
                 - jp branch:          main software
                                       (fork of slgrobotics's
                                        fork of Articulated
                                        Robotics' articubot_one)
                 - exploration branch: house exploration +
                                       mapping code (currently
                                       running on Stormy; not
                                       yet merged to jp)
             Motor driver: https://github.com/JHPHELAN/roboclaw_driver
                           (fork of wimblerobotics/roboclaw_driver)
             Dotfiles (private):
               https://github.com/JHPHELAN/stingray-dotfiles

Purpose:     If the SD card dies tomorrow, this document is
             how Stormy gets rebuilt.  Present-tense, imperative,
             subsystem-oriented.  Every procedure is one that
             has been executed successfully on the real robot.

Companion:   Stingray_Field_Notes.txt (105 lessons + indexes)
             Stingray_Curation_Notes.txt (17 chunks raw
             stardated distillate from the source log)
             Stingray Experience.wpd (source log,
             2023.05.06 - 2026.07.11, 832 pp)

Style:       Plain text.  No markdown.  "====" dividers between
             chapters, "----" between sections.  Command blocks
             indented.  File paths use $HOME or explicit
             /home/ubuntu/ where the tilde matters.

Placeholder key (values in <ANGLE_BRACKETS> are placeholders;
substitute your own before running any command that includes
one):

    <ROBOT_ETH_IP>          Stingray wired ethernet address
    <ROBOT_WIFI_IP>         Stingray USB WiFi dongle address
    <ROBOT_WLAN_IP>         Stingray onboard WiFi (disabled;
                            noted for older recipes only)
    <LINUXBOX_ETH_IP>       LinuxBox ethernet address
    <LINUXBOX_WIFI_IP>      LinuxBox WiFi address
    <WORKSTATION_IP>        Windows workstation address
    <ROUTER_IP>             LAN gateway
    <ROBOT_STATIC_A>        Stingray netplan static address (A)
    <ROBOT_STATIC_B>        Stingray netplan static address (B)
    <DHCP_POOL_RANGE>       Your router's DHCP client range
    <HOME_SSID>             Your home WiFi SSID
    <USB_WIFI_IFACE>        Interface name of the USB WiFi
                            dongle on your Pi (Ubuntu names it
                            wlx<mac>; will differ per adapter)
    <DECO_OUI>              OUI of your TP-Link Deco mesh nodes
                            (first three MAC octets)
    <DECO_A_MAC>            Base MAC of Deco node A
    <DECO_A_2G_TAIL>        Last two octets of Deco A's 2.4 GHz
                            BSSID (= base + 2)
    <DECO_A_5G_TAIL>        Last two octets of Deco A's 5 GHz
                            BSSID (= base + 3)
    ...B, C follow the same pattern for additional Deco nodes.

All IPs, MAC addresses, SSIDs, and MAC-derived interface names
in this Manual are placeholders.  This is a builder's manual;
the specific values on the author's home LAN are neither
interesting to a reader nor safe to publish.

================================================================
TABLE OF CONTENTS
================================================================

CHAPTER  0    How to use this manual
CHAPTER  1    Origin - the story of Stormy
CHAPTER  2    Current hardware summary
CHAPTER  3    Power system
CHAPTER  4    Drivetrain - motors, encoders, RoboClaw
CHAPTER  5    Compute - Raspberry Pi 5
CHAPTER  6    IMU - BNO085
CHAPTER  7    LiDAR - Youyeetoo FHL-LD19
CHAPTER  8    Camera - Luxonis OAK-D
CHAPTER  9    Networking
CHAPTER 10    Base OS install and ROS 2 Jazzy setup
CHAPTER 11    Workspace, repos, and build
CHAPTER 12    URDF and robot description
CHAPTER 13    Nav2, SLAM Toolbox, AMCL - configuration
CHAPTER 14    Mapping workflow (blueprint + hybrid)
CHAPTER 15    Autonomous exploration
CHAPTER 16    Indicators - headlights, beacon, audio
CHAPTER 17    Three-machine operation (Stingray + LinuxBox + Hank Rearden)
CHAPTER 18    CycloneDDS unicast peer discovery
CHAPTER 19    Daily operations - aliases, tasks, StormyUp
CHAPTER 20    Backup and disaster recovery
CHAPTER 21    Post-disaster full-rebuild recipe
CHAPTER 22    Diagnostics and troubleshooting reference

APPENDIX A    Bill of materials with sourcing links
APPENDIX B    Xbox controller mapping
APPENDIX C    12-bug motor-driver checklist
APPENDIX D    AMCL tuning reference
APPENDIX E    Reference command cheat sheet
APPENDIX F    People and collaborators
APPENDIX G    Diagrams and photos

================================================================
CHAPTER 0 - HOW TO USE THIS MANUAL
================================================================

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

================================================================
CHAPTER 1 - ORIGIN
================================================================

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

Key collaborators:

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

Named AI collaborators (chronological era):

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

Milestones worth remembering:

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

================================================================
CHAPTER 2 - CURRENT HARDWARE SUMMARY
================================================================

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

----------------------------------------------------------------
2.1  Physical dimensions and mass
----------------------------------------------------------------

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

----------------------------------------------------------------
2.2  Power (see Chapter 3)
----------------------------------------------------------------

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

----------------------------------------------------------------
2.3  Drivetrain (see Chapter 4)
----------------------------------------------------------------

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

----------------------------------------------------------------
2.4  Compute (see Chapter 5)
----------------------------------------------------------------

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

----------------------------------------------------------------
2.5  IMU (see Chapter 6)
----------------------------------------------------------------

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

----------------------------------------------------------------
2.6  LiDAR (see Chapter 7)
----------------------------------------------------------------

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

----------------------------------------------------------------
2.7  Camera (see Chapter 8)
----------------------------------------------------------------

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

----------------------------------------------------------------
2.8  Network (see Chapters 9 and 18)
----------------------------------------------------------------

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

================================================================
CHAPTER 3 - POWER SYSTEM
================================================================

----------------------------------------------------------------
3.1  Topology (current, 2026-09-20)
----------------------------------------------------------------

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

----------------------------------------------------------------
3.2  Emergency stop + remote kill switch (two distinct devices)
----------------------------------------------------------------

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

Both should be tested with motors running before every
significant demo or public run.

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

----------------------------------------------------------------
3.3  Shunt Regulator - Pololu 3779
----------------------------------------------------------------

Formula (Pololu spec):
    trip_voltage = (Vbatt_nominal) * 1.10

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

----------------------------------------------------------------
3.4  Common power symptoms and fixes
----------------------------------------------------------------

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

================================================================
CHAPTER 4 - DRIVETRAIN
================================================================

----------------------------------------------------------------
4.1  Motors
----------------------------------------------------------------

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

----------------------------------------------------------------
4.2  Encoders
----------------------------------------------------------------

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

Set `quad_pulses_per_meter: 8226` and
`quad_pulses_per_revolution: 3200` in the roboclaw driver
config yaml (Chapter 4.4).

----------------------------------------------------------------
4.3  Wiring - motors and encoders
----------------------------------------------------------------

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

----------------------------------------------------------------
4.4  RoboClaw configuration
----------------------------------------------------------------

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

RoboClaw General Settings (via BasicMicro Motion Studio OR
Wimble's roboclaw_studio):

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

Save all settings to EEPROM after edits.  Power-cycle
and verify persistence.

----------------------------------------------------------------
4.5  PID tuning
----------------------------------------------------------------

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

    M2 (right):
        P:      1.12181
        I:      0.17827
        D:      0.0
        QPPS:  17381

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

----------------------------------------------------------------
4.6  Driver package
----------------------------------------------------------------

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

Config file location:
    robots/stingray/config/roboclaw.yaml

Full contents (canonical):

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

        # Publishing rates
        odometry_rate: 67.0        # Hz
        joint_states_rate: 30.0
        status_rate: 10.0

        # Robot geometry
        wheel_radius: 0.0619
        wheel_separation: 0.26
        encoder_counts_per_revolution: 3200

        # Frames
        base_frame: "base_link"
        odom_frame: "odom"

        # Safety
        max_angular_velocity: 0.7
        max_linear_velocity: 0.3
        max_seconds_uncommanded_travel: 0.05

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

        # Motor accel
        accel: 3000

        # Publishing controls
        publish_odom: true
        publish_tf:   false        # EKF publishes odom->base_link
        publish_joint_states: true

        # Debug (keep FALSE in production)
        do_debug: false
        do_low_level_debug: false

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

    params_file = PathJoinSubstitution([
        FindPackageShare('articubot_one'),
        "robots", "stingray", "config", "roboclaw.yaml"
    ])

----------------------------------------------------------------
4.7  Twist vs TwistStamped
----------------------------------------------------------------

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

Verify:
    ros2 topic info -v /diff_cont/cmd_vel

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

----------------------------------------------------------------
4.8  Per-board main-battery voltage calibration
----------------------------------------------------------------

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

Fix:  the driver applies a two-parameter linear correction
before publishing:

    reported = raw/10.0 * main_battery_scale + main_battery_offset

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

================================================================
CHAPTER 5 - COMPUTE (Raspberry Pi 5)
================================================================

----------------------------------------------------------------
5.1  Hardware
----------------------------------------------------------------

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

----------------------------------------------------------------
5.2  UART configuration for RoboClaw
----------------------------------------------------------------

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

Correct `/boot/firmware/config.txt` snippet:

    [pi5]
    enable_uart=1
    dtoverlay=uart0-pi5
    dtoverlay=uart1-pi5    # optional; uart1 also
                            # available if needed

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

Reboot after either change.

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

The `ubuntu` user is added to `dialout` by default on
Ubuntu 24.04.

----------------------------------------------------------------
5.3  EEPROM and boot configuration
----------------------------------------------------------------

Enable full 5 A current draw:

    sudo rpi-eeprom-config --edit
    # Add:  PSU_MAX_CURRENT=5000

Also in config.txt:
    usb_max_current_enable=1

Verify after reboot:
    sudo vcgencmd get_config usb_max_current_enable
    # -> usb_max_current_enable=1

For NoMachine / headless HDMI framebuffer:

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

----------------------------------------------------------------
5.4  Diagnostic commands (adopted from Sergei)
----------------------------------------------------------------

Run these after ANY power-topology change:

    # Verify full 5 A draw allowed:
    sudo vcgencmd get_config usb_max_current_enable

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

    # See USB device MaxPower draws (spot the offenders):
    lsusb -v 2>&- | grep -E 'Bus 00|MaxPower'

================================================================
CHAPTER 6 - IMU (BNO085)
================================================================

----------------------------------------------------------------
6.1  Hardware
----------------------------------------------------------------

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

----------------------------------------------------------------
6.2  Driver
----------------------------------------------------------------

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

----------------------------------------------------------------
6.3  Configuration
----------------------------------------------------------------

Config file:
    robots/stingray/config/bno085_i2c.yaml

Full contents (canonical as of 2026-08-31):

    bno08x_driver:
      ros__parameters:
        frame_id: "imu_link"

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

        # I2C interface
        i2c:
          enabled: true
          bus: "/dev/i2c-1"
          address: "0x4A"

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

----------------------------------------------------------------
6.4  EKF integration
----------------------------------------------------------------

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

Key IMU section:

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

----------------------------------------------------------------
6.5  Verification
----------------------------------------------------------------

Bench verify (before mounting):

    sudo i2cdetect -y 1
    # Should show "4a" at row 40, column a

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

================================================================
CHAPTER 7 - LIDAR (Youyeetoo FHL-LD19)
================================================================

----------------------------------------------------------------
7.1  Hardware
----------------------------------------------------------------

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

----------------------------------------------------------------
7.2  udev rule (persistent device name)
----------------------------------------------------------------

Rules file (consolidated 2026.06.29):
    /etc/udev/rules.d/99-robot.rules

Content pinning by product string + generic serial "0001":

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

After editing:
    sudo udevadm control --reload-rules && sudo udevadm trigger

Verify:
    ls -l /dev/ldlidar
    # -> lrwxrwxrwx 1 root root 7 ... /dev/ldlidar -> ttyUSB0

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

----------------------------------------------------------------
7.3  Driver
----------------------------------------------------------------

Package:  `ldlidar_ros2`
Repo:     https://github.com/ldrobotSensorTeam/ldlidar_ros2

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

Build:
    cd ~/robot_ws
    colcon build --packages-select ldlidar_ros2

----------------------------------------------------------------
7.4  Launch and static TF
----------------------------------------------------------------

Launch file:  `ldlidar_ros2/launch/ld19.launch.py`

Modify to point at the udev symlink:

    {'port_name': '/dev/ldlidar'},
    {'serial_baudrate': 230400},

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

    arguments=['0', '0', '0.18',
               '0', '0', '-0.7071068', '0.7071068',
               'base_link', 'base_laser']

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

----------------------------------------------------------------
7.5  SLAM Toolbox / Nav2 usage
----------------------------------------------------------------

Scan topic:   `/scan`
Frame ID:     `base_laser`
QoS:          BEST_EFFORT (LD19 default)

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

SLAM Toolbox params to reduce compute load
(`robots/stingray/config/slam_toolbox_params.yaml`, key
values):

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

================================================================
CHAPTER 8 - CAMERA (Luxonis OAK-D)
================================================================

----------------------------------------------------------------
8.1  Hardware
----------------------------------------------------------------

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

----------------------------------------------------------------
8.2  Driver install
----------------------------------------------------------------

Use the apt package, NOT a source clone:

    sudo apt install ros-jazzy-depthai-ros-v3

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

----------------------------------------------------------------
8.3  Configuration
----------------------------------------------------------------

Slim config for Nav2 use (depth-only, low fps, filtered):

Config file:
    robots/stingray/config/oakd_nav_slim.yaml

Key parameters:

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

        rgb:
          i_enable:      false     # not used in slim mode
        left:
          i_enable:      true
        right:
          i_enable:      true

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

    parent_frame:="oakd_front_panel"
    cam_pos_x:=0.0   cam_pos_y:=0.0   cam_pos_z:=0.0

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

----------------------------------------------------------------
8.4  Nav2 obstacle source
----------------------------------------------------------------

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

Live-config sync:  2026-09-11 (nav2_params.yaml on
articubot_one exploration branch @ 96c28e5).

----------------------------------------------------------------
8.5  Mesh and material
----------------------------------------------------------------

Mesh file:  `articubot_one/assets/meshes/OAK-D.dae`

Two rendering-target rules:

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

================================================================
CHAPTER 9 - NETWORKING
================================================================

----------------------------------------------------------------
9.1  Interfaces (current, 2026-07-20)
----------------------------------------------------------------

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

----------------------------------------------------------------
9.2  Disabling wlan0
----------------------------------------------------------------

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

    # Verify:
    hostname -I
    # Should show ONLY <ROBOT_WIFI_IP> (and possibly eth0's
    # <ROBOT_ETH_IP> when docked)

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

----------------------------------------------------------------
9.3  TP-Link Deco mesh layout
----------------------------------------------------------------

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

Node C was relocated on 2026.07.10 for better far-end
coverage.

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

----------------------------------------------------------------
9.4  WiFi monitoring
----------------------------------------------------------------

Live topics (via `wifi_publisher.py` node in
articubot_one/scripts/):

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

Both wlan0 (when up) and wlxUSB publish.  1 Hz.

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

Heat-mapping (Sergei's `wifi_logger_visualizer`, augmented
by JHPHELAN's rainbow-heatmap PR):

    ros2 launch wifi_logger_visualizer wifi_logger.launch.py
    # drive around while it runs; writes to SQLite DB

    ros2 launch wifi_logger_visualizer heat_mapper.launch.py \
         standalone:=true \
         db_path:=/home/ubuntu/robot_ws/src/wifi_logger_visualizer/wifi_data.db

Displays ROYGB rainbow heat map (red = weak, blue = strong)
overlaid on the Nav2 map in RViz2.

================================================================
CHAPTER 10 - BASE OS INSTALL AND ROS 2 JAZZY SETUP
================================================================

Adopt Sergei's ROS Jazzy install guide as the reference:
    https://github.com/slgrobotics/robots_bringup

Below is the post-disaster minimum path validated on
Stormy 2026.06.09.

----------------------------------------------------------------
10.1  OS
----------------------------------------------------------------

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

First boot: complete the Ubuntu setup (user `ubuntu`,
hostname `Stingray`, timezone Central US, keyboard US).

----------------------------------------------------------------
10.2  System updates and base tools
----------------------------------------------------------------

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

Disable unattended-upgrades (prevents surprise ROS/kernel
updates mid-navigation):

    sudo dpkg-reconfigure unattended-upgrades
    # Choose No.

----------------------------------------------------------------
10.3  UART configuration
----------------------------------------------------------------

See Chapter 5.2.  Edit `/boot/firmware/config.txt` and
`/boot/firmware/cmdline.txt`.  Reboot.

----------------------------------------------------------------
10.4  ROS 2 Jazzy install
----------------------------------------------------------------

Add ROS 2 apt sources (using the CORRECT binary-keyring
recipe - Field Note item 38):

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

    sudo rm /etc/apt/trusted.gpg.d/tmp.gpg

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

    sudo apt update

Install Jazzy + build tools:

    sudo apt install -y \
        ros-jazzy-desktop \
        python3-colcon-common-extensions \
        python3-rosdep

Initialize rosdep:

    sudo rosdep init
    rosdep update

Set up shell:

    echo "source /opt/ros/jazzy/setup.bash" >> ~/.bashrc
    source ~/.bashrc

Verify:
    ros2 run demo_nodes_cpp talker
    # Should print "Publishing: 'Hello World: 1'" etc.
    # Ctrl-C to stop.

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

----------------------------------------------------------------
10.5  ROS 2 environment vars
----------------------------------------------------------------

Add to `~/.bashrc`:

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

Install cyclonedds RMW:
    sudo apt install ros-jazzy-rmw-cyclonedds-cpp

See Chapter 18 for `cyclonedds.xml` contents.

----------------------------------------------------------------
10.6  Additional apt packages needed
----------------------------------------------------------------

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

----------------------------------------------------------------
10.7  SSH keys and Git
----------------------------------------------------------------

Generate SSH key (accept defaults, empty passphrase):
    ssh-keygen -t ed25519 -C "ubuntu@Stingray"

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

Configure git:
    git config --global user.name "<YOUR_NAME>"
    git config --global user.email "<YOUR_EMAIL>"

Test:
    ssh -T git@github.com

================================================================
CHAPTER 11 - WORKSPACE, REPOS, AND BUILD
================================================================

----------------------------------------------------------------
11.1  Workspace layout
----------------------------------------------------------------

Canonical name: `~/robot_ws`

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

----------------------------------------------------------------
11.2  Clone all repos
----------------------------------------------------------------

    mkdir -p ~/robot_ws/src && cd ~/robot_ws/src

    git clone git@github.com:JHPHELAN/articubot_one.git
    cd articubot_one && git checkout exploration && cd ..

    git clone https://github.com/JHPHELAN/roboclaw_driver.git

    git clone https://github.com/slgrobotics/bno08x_ros2_driver.git

    git clone https://github.com/ldrobotSensorTeam/ldlidar_ros2.git
    cd ldlidar_ros2 && git submodule update --init --recursive && cd ..

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

----------------------------------------------------------------
11.3  rosdep and build
----------------------------------------------------------------

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

Add to `~/.bashrc`:
    source ~/robot_ws/install/setup.bash

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

----------------------------------------------------------------
11.4  Common build issues
----------------------------------------------------------------

`ldlidar_ros2` `pthread_mutex_init not declared`:
    Add `#include <pthread.h>` to
    `sdk/include/ldlidar_driver/log_module.h`.  Rebuild.

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

Zombie topics on `ros2 topic list`:
    See Chapter 22.2 (zombie cleanup drill).

================================================================
CHAPTER 12 - URDF AND ROBOT DESCRIPTION
================================================================

----------------------------------------------------------------
12.1  Xacro file tree
----------------------------------------------------------------

Location: `robots/stingray/description/`

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

----------------------------------------------------------------
12.2  Key physical dimensions (from stingray_properties.xacro)
----------------------------------------------------------------

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

----------------------------------------------------------------
12.3  Wheel link split (RViz2 multi-visual bug workaround)
----------------------------------------------------------------

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

Joined by FIXED joints (spin propagates through fixed joints
from the parent continuous-joint wheel).

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

----------------------------------------------------------------
12.4  base_footprint size (accounts for OAK-D nose)
----------------------------------------------------------------

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

----------------------------------------------------------------
12.5  Mesh files
----------------------------------------------------------------

Location: `articubot_one/assets/meshes/`
    OAK-D.dae
    Chassis.stl (or similar)

For Gazebo Harmonic compatibility use `file://` URIs (Field
Note item 70), not `package://`:

    <mesh filename="file://$(find articubot_one)/assets/meshes/OAK-D.dae"/>

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

================================================================
CHAPTER 13 - NAV2, SLAM TOOLBOX, AMCL CONFIGURATION
================================================================

----------------------------------------------------------------
13.1  Config files
----------------------------------------------------------------

Location: `robots/stingray/config/`

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

----------------------------------------------------------------
13.2  Nav2 footprint (polygon, 9-vertex)
----------------------------------------------------------------

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

Also enable footprint awareness in MPPI:
    MPPI:
      CostCritic:
        consider_footprint: true

DO NOT combine with non-zero footprint_padding.  See
Field Note item 59.

----------------------------------------------------------------
13.3  Heading overshoot fix (2026.04.12)
----------------------------------------------------------------

Three-part fix (all required):

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

(b) In nav2_params.yaml MPPI section:
        wz_max: 0.25             # was 0.5

(c) In nav2_params.yaml MPPI GoalAngleCritic:
        threshold_to_consider: 0.15    # was 0.5

Result: heading error 2-5 deg (was 20-25 deg).

----------------------------------------------------------------
13.4  Costmap frequencies (Pi 5 tuning)
----------------------------------------------------------------

Reduced to keep TF timing stable during long runs:

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

----------------------------------------------------------------
13.5  KeepOut filter (for coffee-table zones)
----------------------------------------------------------------

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

----------------------------------------------------------------
13.6  SLAM Toolbox
----------------------------------------------------------------

Config: `robots/stingray/config/slam_toolbox_params.yaml`

Key non-default parameters (Field Note item 63):

    max_laser_range:                    8.0
    throttle_scans:                     3
    do_loop_closing:                    true
    correlation_search_space_dimension: 0.5
    num_threads:                        4

Modes:
    make_map:=true       => mode: mapping (build new map)
    make_map:=false      => mode: localization (default;
                            use saved posegraph)

Save aliases (in `~/.bash_aliases` on Stingray):

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

Theta convention: counterclockwise from +X (map East)
toward +Y (map North).  See Field Note item 44.

----------------------------------------------------------------
13.7  AMCL (production localization)
----------------------------------------------------------------

Config: `robots/stingray/config/amcl_params.yaml`

Tuning that handles Stormy's feature-poor open-area (Field Note item 64):

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

----------------------------------------------------------------
13.8  Timestamp cache errors - diagnostic chain
----------------------------------------------------------------

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

       One-time install (both hosts):

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

================================================================
CHAPTER 14 - MAPPING WORKFLOW (BLUEPRINT + HYBRID)
================================================================

----------------------------------------------------------------
14.1  The mapping problem
----------------------------------------------------------------

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

Two scripts do the work:

    articubot_one/assets/maps/blueprint_to_pgm.py
    articubot_one/assets/maps/merge_slam_onto_blueprint.py

----------------------------------------------------------------
14.2  blueprint_to_pgm.py - one-time setup
----------------------------------------------------------------

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

Run:
    cd ~/robot_ws/src/articubot_one/assets/maps
    python3 blueprint_to_pgm.py

Outputs:
    Stormy_blueprint.pgm
    Stormy_blueprint.yaml
    Stormy_blueprint.png

Commit outputs to git.

----------------------------------------------------------------
14.3  Room-by-room mapping cycle
----------------------------------------------------------------

Bash aliases assumed (Chapter 19).

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

----------------------------------------------------------------
14.4  Loop closure discipline
----------------------------------------------------------------

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

----------------------------------------------------------------
14.5  Loading and using the map for production nav
----------------------------------------------------------------

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

The `AMCLtest` alias wraps this command.

================================================================
CHAPTER 15 - AUTONOMOUS EXPLORATION
================================================================

----------------------------------------------------------------
15.1  Tool
----------------------------------------------------------------

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

----------------------------------------------------------------
15.2  Key parameters
----------------------------------------------------------------

In explore.yaml (edit and rerun; six most-used params also
overridable on CLI):

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

----------------------------------------------------------------
15.3  Known issue: cold-start deadlock
----------------------------------------------------------------

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

----------------------------------------------------------------
15.4  Usage
----------------------------------------------------------------

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

Save checkpoints frequently:
    savegraph Stormy_v<NN>

Kill explorer with Ctrl-C in its terminal.  Return Stormy
to dock manually before quitting SLAM.

================================================================
CHAPTER 16 - INDICATORS
================================================================

----------------------------------------------------------------
16.1  Purpose
----------------------------------------------------------------

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

----------------------------------------------------------------
16.2  Hardware (Rev 3, current)
----------------------------------------------------------------

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

Load side (both channels):
    +12V (LiPo bus) -> load ( + ) -> load body -> Drain

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

----------------------------------------------------------------
16.3  Node
----------------------------------------------------------------

Script:  articubot_one/scripts/indicators_node.py
Launch:  articubot_one/robots/stingray/launch/indicators.launch.py
Config:  articubot_one/robots/stingray/config/indicators.yaml

Subscribes:
    /joy                                (sensor_msgs/Joy)
                                        A = headlights ON
                                        B = headlights OFF
                                        X = toggle beacon
                                            SOUND (mute /
                                            unmute the
                                            beacon's WAV;
                                            beacon LED keeps
                                            flashing silently
                                            when muted).
                                            Only meaningful
                                            while the beacon
                                            is on (Y).  Does
                                            NOT mute the Nav2
                                            danger.wav alert.
                                        Y = toggle beacon
                                            (amber strobe +
                                            Klingon audio,
                                            subject to X).
                                            Manual only in
                                            practice - see
                                            /cmd_vel note
                                            below.
    /cmd_vel  (TwistStamped)            Coded: auto-on 2 s
                                        linger after motion.
                                        DE-FACTO DISABLED on
                                        Stormy: the node
                                        subscribes to
                                        /cmd_vel but the
                                        twist chain
                                        (Chapter 4.7)
                                        publishes to
                                        /cmd_vel_joy ->
                                        /diff_cont/cmd_vel,
                                        never /cmd_vel, so
                                        the callback never
                                        fires.  Beacon is
                                        therefore Y-button
                                        only in practice.
    /navigate_to_pose/_action/status    ABORTED goal ->
                                        danger.wav
                                        (alert_on_goal_aborted
                                        DEFAULT off on the
                                        exploration branch;
                                        ABORTED just means
                                        the frontier picker
                                        moves on)
    /behavior_tree_log                  Physical recovery
                                        node (Spin, BackUp)
                                        RUNNING - counted
                                        into a sliding
                                        window.  danger.wav
                                        fires only when the
                                        window fills, i.e.
                                        Nav2 is actually
                                        thrashing.  One-off
                                        Spin / BackUp events
                                        do NOT alert.

Publishes:
    /headlights/state (Bool)
    /beacon/state     (Bool)

Config yaml keys (canonical, from the exploration branch
indicators.yaml as of 2026-08-01):
    # GPIO (BCM numbering)
    headlights_pin:  17           # header pin 11
    beacon_pin:      22           # header pin 15 (LED)
                                  # NOTE: GPIO 22 was the
                                  # Rev 2 piezo; on Rev 3
                                  # the LED moved here and
                                  # BCM 27 is now unused.
    # empty_pin:     27           # header pin 13 (unused)
    headlights_active_low: false  # direct-MOSFET PCB
    beacon_active_low:     false

    # Blink pattern
    beacon_led_on_sec:  1.0
    beacon_led_off_sec: 0.800

    # Boot running-light
    headlights_startup_on_sec: 3.0

    # Beacon audio
    beacon_sound_path: "/home/ubuntu/wav/active/klingon_alert.wav"
    beacon_sound_repeat_sec: 3.6   # matches WAV length
    beacon_sound_device: ""        # "" = aplay default
    beacon_sound_default_on: false # start muted (X toggles)

    # Motion detection (for the coded-but-de-facto-disabled
    # /cmd_vel auto-on described in Subscribes above)
    linear_threshold:  0.01        # m/s
    angular_threshold: 0.05        # rad/s
    beacon_linger_sec: 2.0

    # Joystick button map
    headlights_on_button:  0       # A (green)
    headlights_off_button: 1       # B (red)
    beacon_manual_button:  3       # Y (yellow) - lights
    beacon_sound_button:   2       # X (blue)   - sound

    # Nav2 trouble alert (danger.wav)
    alert_sound_path:  "/home/ubuntu/wav/active/danger.wav"
    alert_sound_device: ""         # "" = follow beacon
    alert_min_interval_sec: 8.0
    alert_on_goal_aborted: false   # exploration: aborts
                                   # are routine, not stuck
    alert_on_recovery:     true
    alert_recovery_node_names:     # substring match
      - "Spin"                     # physical yaw recovery
      - "BackUp"                   # physical reverse
      # Deliberately EXCLUDED (routine, not "stuck"):
      #   ClearEntireCostmap / ClearLocalCostmap /
      #     ClearGlobalCostmap
      #   Wait
    alert_recovery_count_threshold: 3     # burst = STUCK
    alert_recovery_count_window_sec: 30.0
    bt_log_topic:     "/behavior_tree_log"
    nav_status_topic: "/navigate_to_pose/_action/status"

Rationale for the burst threshold: Nav2 fires a one-off
Spin or BackUp all the time as normal self-recovery from
transient bumps against inflated obstacles - that is NOT
stuck.  Only when the robot reaches for physical recoveries
3+ times in 30 s is it genuinely in trouble.  ClearCostmap
and Wait are excluded entirely because they are mild,
routine, and used to flood the speaker in earlier revs.

Beacon-audio sync (2026.05.29 insight): re-anchor the LED
phase to the moment each new WAV clip starts.  Prevents
drift between free-running LED and aplay startup latency.

----------------------------------------------------------------
16.4  WAV file preparation
----------------------------------------------------------------

MP3 -> WAV:
    ffmpeg -i input.mp3 -ar 44100 -ac 2 -sample_fmt s16 output.wav

Boost volume (safe, peak-normalize):
    sox in.wav out_LOUD.wav norm -0.1 gain 6

Boost volume (fast, may clip):
    sox in.wav out_LOUD.wav gain 30

Live volume boost > 100% (GNOME Settings):
    Sound -> Over Amplification: ON
    Slider now goes to 150%.

WAV files in production use live in `~/wav/active/`.  Only
these clips are on the boot / run / alert / shutdown paths,
and only this subdirectory is bundled by the Tier-4b rescue
kit (Chapter 20.6):
    klingon_alert.wav              Beacon (Y button)
    danger.wav                     "Danger Will Robinson" -
                                   Nav2 abort / recovery
    first_call.wav                 Horse-racing bugle used
                                   by the `stingln`
                                   startup alias
    jaws.wav                       Used by the `explore`
                                   alias
    forcefield_powering_down.wav   `scram` (shutdown) alias

`~/wav/` itself is an archive of every sound-effect clip
ever tried (klingon_sensor_alert.wav, melting.wav, and
others).  Nothing in the archive is referenced by any live
config or alias; do not point `beacon_sound_path` or
`alert_sound_path` at it.  To promote a new clip to
production, `cp` it into `~/wav/active/` first and update
the corresponding alias or yaml.

================================================================
CHAPTER 17 - THREE-MACHINE OPERATION
================================================================

----------------------------------------------------------------
17.1  Machines
----------------------------------------------------------------

Stingray (Pi 5 on the robot):
    Hostname:      Stingray
    IPs:           <ROBOT_ETH_IP> (eth0)
                   <ROBOT_WIFI_IP> (wlxUSB)
    Runs:          stingray.launch.py (full robot bringup)
                   indicators.launch.py
                   keepout.launch.py (if using KeepoutFilter)
                   explore (autonomous mapping)
                   foxglove_bridge (Foxglove Studio backend)

LinuxBox (development laptop, wired or WiFi):
    Hostname:      LinuxBox
    IPs:           <LINUXBOX_ETH_IP> (enp3s0f1 ethernet)
                   <LINUXBOX_WIFI_IP> (wlp2s0 WiFi; usually
                                   secondary or disabled)
    Runs:          rviz2 (visualization)
                   plotjuggler (diagnostics)
                   joystick.launch.py (if joystick attached
                                        here instead of Pi)

Hank Rearden (Windows 11 laptop):
    IPs:           <WORKSTATION_IP> (typical)
    Runs:          Foxglove Studio (browser or standalone)
                   PuTTY / VS Code Remote SSH
                   FileZilla (file transfer)
                   CorelDraw (blueprint editing)
                   WordPerfect 2021 (source log editing)
    Dotfiles kit:  hank-rearden-dotfiles/  (see Chapter
                   20.3a).  Captures VS Code config, PuTTY
                   sessions (20+), SSH config, .gitconfig,
                   FileZilla, and extension list.

----------------------------------------------------------------
17.2  Standard launch order
----------------------------------------------------------------

Terminal 1 (Stingray, LAUNCH panel):
    stingln       # add 'slam:=true' for mapping mode
    # Wait for "Creating bond timer" or ~40 s

Terminal 2 (Stingray, INDICATORS panel):
    ros2 launch articubot_one indicators.launch.py

Terminal 3 (Stingray, FOX panel):
    fox           # foxglove_bridge on port 8765

Terminal 4 (Stingray, EXPLORE panel, when mapping):
    explore

Terminal 5 (LinuxBox, JOY panel):
    joy           # Xbox USB receiver dongle lives here;
                  # /joy travels to Stormy over WiFi.
                  # (Launch joy ON Stormy only when the
                  # robot is stuck and you need to walk
                  # behind him with the pad to guide him
                  # out or to the dock.)

Terminal 6 (LinuxBox):
    rviz2

Terminal 7 (Hank Rearden, browser):
    https://app.foxglove.dev  connect to
    ws://<ROBOT_WIFI_IP>:8765

The four Stingray-side terminals (LAUNCH, INDICATORS, FOX,
EXPLORE) are launched by the `StormyUp` VS Code compound
task (Chapter 19.4), from VS Code on Hank Rearden SSH'd
into the Pi.  LinuxBox terminals (JOY, RViz2) are launched
manually - they are NOT part of StormyUp.  Foxglove on Hank
Rearden is opened by hand in a browser.

----------------------------------------------------------------
17.3  Common gotchas
----------------------------------------------------------------

"Frame [map] does not exist" in RViz on LinuxBox but
Stormy is publishing /map correctly:
    See Chapter 18 (CycloneDDS unicast peers).

Foxglove connection fails:
    - Use LAN IP, not localhost (Field Note item 83)
    - Port 8765 (foxglove_bridge), not 9090 (rosbridge)
    - `fox` alias must launch `foxglove_bridge`, not
      `rosbridge_server` (Field Note item 82)

SSH drops during long sessions:
    See Field Note item 84 (SSH keepalive triple).

================================================================
CHAPTER 18 - CYCLONEDDS UNICAST PEER DISCOVERY
================================================================

----------------------------------------------------------------
18.1  Why this exists
----------------------------------------------------------------

TP-Link Deco mesh drops UDP multicast between wired and
wireless clients (Field Note item 78).  ROS 2's default
DDS discovery (SPDP heartbeats) uses multicast.  Result:
`ros2 topic list` on LinuxBox shows 5 topics (its own
daemon defaults) instead of Stormy's ~135.

Fix: use CycloneDDS with an explicit unicast peer list
that bypasses multicast entirely.  Each host connects
directly to every other host's IP.

----------------------------------------------------------------
18.2  Config file
----------------------------------------------------------------

Location: `$HOME/cyclonedds.xml` on EVERY ROS host.

Content (SAME on all hosts EXCEPT the `NetworkInterface
name` line, which differs per host):

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

Per-host `<IFACE>` value:
    Stingray:     <USB_WIFI_IFACE>
    LinuxBox:     enp3s0f1

----------------------------------------------------------------
18.3  Environment
----------------------------------------------------------------

Add to `~/.bashrc` on EVERY ROS host:

    export CYCLONEDDS_URI=file://$HOME/cyclonedds.xml
    export RMW_IMPLEMENTATION=rmw_cyclonedds_cpp

Then:
    source ~/.bashrc
    ros2 daemon stop && ros2 daemon start
    # (kills stale daemon so it picks up new URI)

Verify:
    echo $CYCLONEDDS_URI
    # Should print: file:///home/ubuntu/cyclonedds.xml

    ros2 topic list | wc -l
    # Should be ~135 when Stormy is running its full stack.
    # 5 means discovery failed - check XML syntax.

----------------------------------------------------------------
18.4  Adding a third host
----------------------------------------------------------------

If you add a third ROS host, add its IP to `<Peers>` on
ALL hosts.  Update cyclonedds.xml everywhere.  Restart
ros2 daemon on each.

The dotfiles repo has the canonical file - after editing,
sync to all machines via `sync-to-live.sh`.

================================================================
CHAPTER 19 - DAILY OPERATIONS
================================================================

----------------------------------------------------------------
19.1  Bash aliases (~/.bash_aliases)
----------------------------------------------------------------

Backed up in the `stingray-dotfiles` GitHub repo.  Current
canonical set on Stingray:

    # Build / source
    alias build='cd ~/robot_ws && colcon build && source ./install/setup.bash'
    alias artbld='cd ~/robot_ws/ && colcon build --packages-select articubot_one'
    alias src='source ./install/setup.bash'

    # Launches
    alias joy='ros2 launch articubot_one joystick.launch.py'
    alias stingln='aplay -q ~/wav/active/first_call.wav & \
                   ros2 launch articubot_one stingray.launch.py'
    # For mapping mode, pass slam:=true as a trailing arg,
    # e.g. `stingln slam:=true` - bash aliases forward
    # trailing tokens to the launch command unchanged.
    alias AMCLtest='ros2 launch articubot_one stingray.launch.py \
                     localizer_type:=amcl \
                     map:=/home/ubuntu/robot_ws/src/articubot_one/assets/maps/Stormy_merged.yaml'
    alias anchorln='python3 ~/robot_ws/src/articubot_one/scripts/anchor_display.py'
    alias explore='aplay -q ~/wav/active/jaws.wav & \
                   ros2 launch articubot_one explore.launch.py'
    alias keepout='ros2 launch articubot_one keepout.launch.py'
    alias fox='ros2 launch foxglove_bridge foxglove_bridge_launch.xml'
    alias wifi='ros2 run articubot_one wifi_publisher.py'

    # Anchors (per-waypoint nav goals)
    alias dock='ros2 action send_goal /navigate_to_pose ...'
    alias anchor0='...'    # dock (0, 0, 0)
    alias anchor1='...'    # first anchor (1.32, 1.32, pi/4)
    # ... (through anchor11; see anchor_display.py source
    #      for the full list)

    # Map save/load functions (see Chapter 13.6)
    savemap()   { ...  }
    savegraph() { ...  }
    loadgraph() { ...  }
    merge()     { ...  }
    mapckpt()   { ...  }   # save with timestamped filename

    # Shutdown
    alias scram='aplay -q ~/wav/active/forcefield_powering_down.wav; \
                 sudo shutdown -h now'

    # Volume for whichever USB audio device is default.
    # In PipeWire only one sink is default at a time, so
    # this same alias governs BOTH the USB earbuds (when
    # plugged in for headless testing) and the indicators
    # USB-DAC + speaker used by Stormy (when the earbuds
    # are unplugged).  Check `wpctl status` to confirm
    # which sink is currently @DEFAULT_AUDIO_SINK@.
    earvol() {
        local v="${1:-40}"
        [[ "$v" == *% ]] || v="${v}%"
        wpctl set-volume @DEFAULT_AUDIO_SINK@ "$v"
        wpctl get-volume @DEFAULT_AUDIO_SINK@
    }

----------------------------------------------------------------
19.2  Environment (~/.bashrc appended)
----------------------------------------------------------------

    source /opt/ros/jazzy/setup.bash
    source ~/robot_ws/install/setup.bash

    export RMW_IMPLEMENTATION=rmw_cyclonedds_cpp
    export CYCLONEDDS_URI=file://$HOME/cyclonedds.xml
    export LC_COLLATE=C.UTF-8
    export PATH="$HOME/.local/bin:$PATH"

    # On LinuxBox additionally (for Gazebo Harmonic):
    export QT_QPA_PLATFORM=xcb

    # Load aliases
    if [ -f ~/.bash_aliases ]; then . ~/.bash_aliases; fi

----------------------------------------------------------------
19.3  ~/.inputrc (attempted bracketed-paste fix)
----------------------------------------------------------------

    set enable-bracketed-paste on

Intended to stop the terminal from glitching on long pastes
(2026.06.29 experiment).  Effectiveness unconfirmed - the
"fix" is NOT reliably observed in practice, especially
inside VS Code's integrated terminal.  Left in place because
it does no harm, but do not count on it.

----------------------------------------------------------------
19.4  VS Code StormyUp task
----------------------------------------------------------------

Location: `~/.vscode/tasks.json` on Stingray

Defines dedicated-panel bash terminals:
    FOX, SLAM, KEEPOUT, EXPLORE, WORKSPACE, WAV

(TODO: current tasks.json still declares a JOY panel from
the pre-2026.07 era.  Delete it - the `joy` alias runs on
LinuxBox in the standard workflow (Chapter 17.2, Chapter
19.5).  EXPLORE panel is the one Stormy actually needs on
the robot side.)

Compound task `StormyUp` runs them all in parallel.

Trigger: Ctrl+Shift+P -> "Tasks: Run Task" -> StormyUp.

Full tasks.json is preserved in the stingray-dotfiles repo.

----------------------------------------------------------------
19.5  Xbox controller pairing
----------------------------------------------------------------

USB Xbox receiver dongle lives on LinuxBox (see Chapter
17.2).  Pair the controller there, not on Stormy: turn on
the controller; the dongle's pair LED will start flashing;
press the small ))) button on the front of the controller;
the pair completes.  Silver button in the middle of the
controller will light steadily when paired.

/joy travels from LinuxBox to Stormy over the CycloneDDS
unicast peer list (Chapter 18).  Move the dongle to Stormy's
powered USB hub only for the walk-behind-and-guide-him-out
situations described in Chapter 17.2.

Trouble pairing (Field Note recurring):
    Try a fresh set of AA batteries in the controller.
    Try swapping the battery case with a known-good
    controller.

Verify (on whichever host is currently hosting the dongle):
    ros2 run joy joy_enumerate_devices
    # Should list the pad
    ros2 topic echo /joy
    # Buttons and axes should respond

================================================================
CHAPTER 20 - BACKUP AND DISASTER RECOVERY
================================================================

READ THIS BEFORE YOU TOUCH `rsync`, `dd`, OR ANY DESTRUCTIVE
COMMAND, AI-GENERATED OR OTHERWISE.

----------------------------------------------------------------
20.1  The rule
----------------------------------------------------------------

If it isn't on GitHub, it doesn't exist (Field Note item
88).  End every substantive session with:

    cd ~/robot_ws/src/articubot_one
    git add -A
    git commit -m "descriptive message"
    git push

Same rule for the `roboclaw_driver` fork, the
`stingray-dotfiles` repo, and any other tracked source tree.

----------------------------------------------------------------
20.2  What to back up
----------------------------------------------------------------

Tier 1 - always on GitHub, daily commits:
    articubot_one         (code, launch files, config yaml,
                           URDF, maps, docs)
    roboclaw_driver       (JHPHELAN fork with fixes)
    stingray-dotfiles     (bash aliases, tasks.json,
                           cyclonedds.xml, udev rules)

Tier 2 - periodic (weekly) full-disk image to external USB:
    Complete NVMe image via `dd | gzip` (Chapter 20.4)

Tier 3 - snapshots before invasive changes:
    Before swapping IMU/LiDAR, changing power topology,
    changing kernel, or doing anything invasive - snapshot
    the SSD.

----------------------------------------------------------------
20.3  The dotfiles repo
----------------------------------------------------------------

    https://github.com/JHPHELAN/stingray-dotfiles  (private)

Contents:
    ~/.bash_aliases
    ~/.bashrc
    ~/.inputrc
    ~/.gitconfig
    ~/.ssh/authorized_keys
    ~/cyclonedds.xml
    ~/.vscode/tasks.json
    /etc/udev/rules.d/99-robot.rules
    /etc/udev/rules.d/80-movidius.rules
    /etc/netplan/01-network-config.yaml    (be cautious with
                                            this one - it
                                            contains WiFi PSK)

With:
    sync-from-live.sh    Pulls current live files into repo
    sync-to-live.sh      Pushes repo files to system.
                         Default is DRY-RUN.
                         Use `--apply` to actually write.
    README.md

To back up current live configs to the repo:
    cd ~/stingray-dotfiles
    ./sync-from-live.sh
    git add -A && git commit -m "sync $(date +%Y-%m-%d)" && git push

To restore configs from the repo:
    cd ~/stingray-dotfiles
    git pull
    ./sync-to-live.sh --apply

----------------------------------------------------------------
20.3a  Hank Rearden (Windows) dotfiles kit
----------------------------------------------------------------

Hank Rearden holds material that would be catastrophic to lose:
the WordPerfect diary (source log), all CorelDraw blueprints,
the Photos/ and ScreenShots/ project folders, 20 PuTTY sessions,
FileZilla site manager, and months of VS Code tuning.  The
kit that captures Hank Rearden's configuration layer is:

    hank-rearden-dotfiles/
        README.md
        .gitignore
        sync-from-live.ps1
        sync-to-live.ps1
        dotfiles/                       populated by
                                        sync-from-live -Apply

Intended to live on GitHub as `hank-rearden-dotfiles` (PRIVATE),
mirroring the `stingray-dotfiles` pattern but for Windows 11.

What it captures (default set):
    %USERPROFILE%\.ssh\config
    %USERPROFILE%\.ssh\known_hosts
    %USERPROFILE%\.gitconfig
    %APPDATA%\Code\User\settings.json
    %APPDATA%\Code\User\keybindings.json
    %APPDATA%\Code\User\chatLanguageModels.json
    %APPDATA%\Code\User\snippets\*
    output of `code --list-extensions`
    export of HKCU:\Software\SimonTatham\PuTTY\Sessions
    %APPDATA%\FileZilla\filezilla.xml

Sensitive-file (marked `Sensitive: $true` in the manifest,
skipped by default):
    %APPDATA%\FileZilla\sitemanager.xml
      (site manager contains hostnames + usernames + possibly
       cached passwords for every FTP/SFTP site)

Usage (PowerShell in the repo directory):

    # Snapshot live -> repo (dry run):
    .\sync-from-live.ps1
    # Snapshot for real:
    .\sync-from-live.ps1 -Apply
    # Include sensitive files:
    .\sync-from-live.ps1 -Apply -IncludeSensitive

    # Restore repo -> live (dry run):
    .\sync-to-live.ps1
    # Restore for real:
    .\sync-to-live.ps1 -Apply
    # Restore including sensitive:
    .\sync-to-live.ps1 -Apply -IncludeSensitive

Content layer (WordPerfect diary, CorelDraw files, Photos,
etc.) is handled separately by OneDrive sync.  Both layers
are needed.

Full documentation in hank-rearden-dotfiles/README.md,
including the post-Windows-reinstall recovery playbook.

----------------------------------------------------------------
20.4  NVMe full-disk backup recipe
----------------------------------------------------------------

Weekly Tier-2 backup of Stormy's NVMe SSD to an external
exFAT USB HDD.  Two flavors below:

  Section A - the full step-by-step for a weekly backup
              (this is what you do most of the time).
  Section B - one-time drive format (only when you first
              prepare a new backup HDD, or when you retire
              an old one).
  Section C - restore.

Reference values used throughout (Stormy 2026-09):
    Backup HDD label:  STORMYBAK  (exFAT)
    Backup HDD device: /dev/sda   (partition /dev/sda1)
    Mount point:       /mnt/backup
    NVMe boot part:    /dev/nvme0n1p1  (~500 MB, mounted /boot/firmware)
    NVMe root part:    /dev/nvme0n1p2  (~238 GB, mounted /)
    Files written:     /mnt/backup/nvme_boot_YYYY-MM-DD.img.gz
                       /mnt/backup/nvme_root_YYYY-MM-DD.img.gz

Substitute your own device letters and mount label if
different; verify with `lsblk` and `sudo blkid` before
running any `dd` command.

Two ways to run the weekly backup:

  * Automated (preferred).  Run `diskbackup` on Stormy - it
    wraps the whole Section A workflow, images both
    partitions, verifies gzip integrity, computes the raw
    throughput, appends a new row to BACKUPS.md (which
    lives inside this repo) with an automatic git push,
    and unmounts /mnt/backup at the end so STORMYBAK is
    safe to unplug (pass `--no-unmount` to skip that last
    step if you plan to chain another operation).  Add
    `--verify` to also run the full four-layer integrity
    check (gzip -t on both, sha256 cross-check against the
    Tier 4a copy on Hank Rearden, `fsck.exfat -n`) after
    the image + upload complete - adds ~20 min unattended.
    See tools/backup_disk.sh and the "diskbackup" alias
    line in Chapter 19.1.

  * Verify only (standalone).  Run `verify` on Stormy to
    check any existing image pair on the mounted HDD -
    defaults to today's date, or pass `verify YYYY-MM-DD`
    for older ones, `--latest` to auto-pick the newest
    pair, `--local-only` to skip the iCloud cross-check.
    See tools/verify_images.sh.

  * Manual step-by-step (Section A below).  Kept as the
    canonical reference for what the automated wrapper does
    under the hood, and for the disaster case when the
    script isn't available (post-rebuild, before you have
    cloned this repo onto a fresh SSD).

Either way, the resulting files land at the same paths and
BACKUPS.md gets the same six columns.  Only the typing
count differs.

----------------------------------------------------------------
Section A - Weekly backup, step by step
----------------------------------------------------------------

Assumes the HDD from the previous week is available and
already formatted exFAT with the STORMYBAK label (or
whatever label you chose in Section B).

A1.  Plug the HDD into Stormy.
     - Use a blue USB 3.0 port DIRECTLY on the Pi 5.  Not through
       a hub - bus-powered HDDs disconnect mid-copy over long
       runs (Field Note item 86).
     - If your enclosure has its own AC adapter, use it.
     - Wait ~10 seconds for the Pi to enumerate the device.
     - One-time setup for Sabrent USB 3 enclosures (JMicron
       152d:a578): add `usb-storage.quirks=152d:a578:u` to
       /boot/firmware/cmdline.txt and reboot, otherwise heavy
       reads (scp for Tier 4a) will bus-reset the drive.  See
       Field Note item 106 for the full symptom + fix.

A2.  Open a shell on Stormy.  SSH from your workstation, or use
     Stormy's own console.  Optional: wrap in tmux so an SSH drop
     doesn't kill the 40-minute job.

         sudo apt install -y tmux     # once, if not present
         tmux new -s backup           # detach: Ctrl-b then d
                                      # reattach: tmux attach -t backup

A3.  Locate the HDD.  Run:

         lsblk -o NAME,SIZE,LABEL,FSTYPE,MOUNTPOINT
         sudo blkid /dev/sda1
         lsblk -o NAME,SIZE,MOUNTPOINT /dev/nvme0n1

     Confirm before continuing:
       - `blkid` prints  TYPE="exfat"  and  LABEL="STORMYBAK".
       - Backup HDD is /dev/sda1  (a second USB drive shifts it to
         /dev/sdb1 - do not assume, check).
       - NVMe shows  nvme0n1p1 on /boot/firmware  and
         nvme0n1p2 on /.
     If any of those is off, STOP.  A wrong device letter later is
     disastrous.

A4.  Mount the HDD.

     If /etc/fstab has an `x-systemd.automount` entry for
     LABEL=STORMYBAK (see Field Note item 108 for the one-time
     install), skip this step entirely - the drive will be
     mounted transparently the moment `diskbackup` or any
     other process touches /mnt/backup, and unmounted after
     5 minutes of inactivity.  Verify with:

         findmnt -t exfat /mnt/backup   # expect one line

     Otherwise, mount manually:

         sudo mkdir -p /mnt/backup
         sudo mount /dev/sda1 /mnt/backup
         mount | grep sda1
         df -h /mnt/backup
         ls -lh /mnt/backup

     Confirm before continuing:
       - `mount | grep sda1` prints  type exfat  (NOT fuseblk).
       - `df -h` shows ~15 GB or more free (need ~15 GB per pair;
         a 150 GB drive holds ~8-10 weekly generations).
       - `ls -lh` shows the previous week's images - proves you
         mounted the right drive.
     Do NOT pass `-t exfat` on the mount command.  The kernel
     exfat driver autoloads on Ubuntu 24.04; `-t exfat` invokes
     the userspace helper `mount.exfat` which is not installed
     (Field Note item 104).

A5.  Filenames (nothing to run - just note the convention):

         /mnt/backup/nvme_boot_YYYY-MM-DD.img.gz
         /mnt/backup/nvme_root_YYYY-MM-DD.img.gz

     Timestamps prevent overwriting last week's good backups if
     today's run fails partway through.

A6.  Boot partition first (~2 minutes).  Run:

         sudo sh -c 'dd if=/dev/nvme0n1p1 bs=4M \
                         conv=sync,noerror status=progress \
                         | gzip -1 \
                         > /mnt/backup/nvme_boot_$(date +%F).img.gz'

     Then verify:

         gzip -t /mnt/backup/nvme_boot_$(date +%F).img.gz && echo BOOT_OK
         ls -lh /mnt/backup/nvme_boot_$(date +%F).img.gz

     Expected: `BOOT_OK` and file size ~150-170 MB.  If much

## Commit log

2026-08-08 Add LICENSE (CC BY 4.0), populate Appendix G images
    - LICENSE: full canonical CC BY 4.0 legal code
    - README.md: TBD license -> CC BY 4.0 attribution block
    - images/: 8 approved images copied in from workspace
    - Appendix G intro: files now live in images/ (self-contained)
    - Appendix G TODO block: sweep done; deferred update-needed list
    - G.1: path updated to images/WIRING.jpg
    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
2026-08-13 Add KiCad schematic source + Appendix G.9
    - kicad/Stingray/ - KiCad 10.0 project (schematic, custom symbols, sym-lib-table). Schematic resaved in 10.0 (generator_version 10.0, version 20260306) as first commit.
    - images/Stormy Schematic 2026-08-12.png - PNG export of the full schematic (power, kill, motors, compute, sensors)
    - Appendix G.9 entry with in-repo Source path and Ch 2/3/4/5/6 refs
    - .gitignore: KiCad per-user prefs, backups, cache, autosaves, lock files
    - Drop superseded 2025.04.07 StingraySchematic PDF from deferred block
    Known cosmetic: 'Unexpected version' banner on load, fired by Stingray-eagle-import.kicad_sym (still generator_version 8.0). Only used for VCC (6 refs); sl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
    [Stingray.kicad_pcb, Stingray.kicad_sch]
2026-09-07 docs: FN proofread pt 1 (items 1-~64) + Manual Ch 3.1 STPS source-OR-ing target-topology; kicad Dual Power Input WIP; establish Recap/Remember/Push handoff ritual
    [Dual Power Input.kicad_pcb, Dual Power Input.kicad_sch, Stingray.kicad_sch]
2026-09-07 docs: FN proofread pt 2 (items 65-104 + indices)
    - item 72: spell out DAE (Digital Asset Exchange / Collada) on first use
    - item 75: title CENTER -> TOP to match body (1.5 mm BELOW the LD19 cylinder's top)
    - item 77: BROKEN BY DESIGN -> DISABLED BY DESIGN (reversible, more accurate)
    - item 81: spell out full sudo nmcli re-enable commands
    - item 82: replace 'Enable Assets' wave-of-hand with asset_uri_allowlist mechanism; flag as not verified on Stormy
    - item 97: keep filename on continuous line
    - item 103: spell out WMMHR-2025 (World Magnetic Model High Resolution) on first use
2026-09-07 docs: Manual Ch 20.4 rewritten as explicit step-by-step
    Restructured 20.4 into three labelled sections:
    A. Weekly backup - step-by-step (A1-A9) covering plug-in, tmux, mount without -t exfat per FN 104, boot-first pipeline order, timestamped filenames via date +%F, gzip -t verify, clean unmount, log en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
    B. One-time drive format (only for a fresh HDD).
    C. Restore.
    Encodes today's actual working procedure with STORMYBAK (label + /dev/sda1 + /mnt/backup as canonical values); prior wording assumed GNOME auto-mount which SSH sessions never see.
2026-09-07 docs: Manual Ch 20.4 A3 tightening + Section A/B/C H4 render fix
    - build_readme.py: added SUBSECTION_RE for 'Section X - ...' divider-wrapped labels; emit as H4 (was falling into the generic-fallback and rendering as H2 above their own 20.4 parent).
    - Ch 20.4 Section A step A3: reformatted to one-line intent -> command block -> bulleted checklist -> STOP condition; commands are now a scannable code block instead of prose-inline.
2026-09-11 v1.1 public release: doc sync + private-data scrub
    SOFTWARE SYNC (five items reflecting Aug-Sep 2026 commits on articubot_one/exploration and roboclaw_driver/feat branches):
    * Ch 6.2 + 6.3 - BNO085 enable_6dof_mode: true (SH-2 mag calibration doesn't complete on Stormy) and 2s TimerAction I2C-race defense. FN 32 mount-location corrected: BNO085 breakout is at base_link between the drive motors, NOT on the OAK-D deck (the OAK-D's internal BNO086 was abandoned; see FN 68).
    * Ch 8.4 + FN 61 - Rewrote to reflect live 2026-07-06 tuning: min_obstacle_height 0.10 on global costmap (with 10-line ground-noise accumulation rationale), 0.02 on local. Withdrew observation_persistence: 1.5 advice as ne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
2026-09-11 docs: correct articubot_one attribution chain (Ch 1 + Appendix F)
    Sergei Grichine (slgrobotics) is the MAINTAINER of a fork, not the author of articubot_one. Original: Josh Newans / Articulated Robotics at github.com/joshnewans/articubot_one. Sergei forked and adapted it for his own robot PLUCKY; Stormy is a further fork of Sergei's fork. Fixed both the Ch 1 collaborator paragraph and the Appendix F entry to make the chain explicit.
2026-09-12 docs: reword 1/4 in acrylic note - online listings say 6 mm (Ch 2.1)
2026-09-12 docs: LD19 LiDAR plugs directly into Pi USB 2.0, not the hub (Ch 3.1)
2026-09-12 docs: tighten Ch 3-4 prose, fix 52Pi->USB-C and LiPo (not LiFePO4)
2026-09-13 backup infra: automated Tier-2 wrapper, off-site tier scripts, WAV migration
    * New tools/backup_disk.sh: automated Section A - dd|gzip both partitions, verify gzip -t, compute MB/s + link speed, append row to BACKUPS.md, git commit + push.
    * BACKUPS.md moved into repo (from workspace root); backup_disk.sh auto-updates it.
    * New tools/hank_prune_dropbox.ps1 for Task-Scheduler-driven Dropbox pruning.
    * bundle_rescue_kit.sh: drop docs (already in git + OneDrive), retarget WAV to ~/wav/active/, auto-prune local kits > 28d after each write.
    * backup_check.sh: every WARN row now prints an actionable remediation string.
    * WAV migration to ~/wav/active/: only 5 production clips ship in Tier 4b.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
2026-09-13 scp automation: rescue and diskbackup push directly to Hank Rearden
    * bundle_rescue_kit.sh: after write + prune, scp tarball to hankrearden:Dropbox/Stormy/ via SSH alias. Graceful fallback if SSH is offline (keeps local tarball, prints WARN).
    * backup_disk.sh: new --icloud flag. When set, scp both nvme_*.img.gz files to hankrearden:iCloudDrive/Stormy/ and auto-touch the Tier-4a stamp.
    * Ch 20.6 install section: recipe for OpenSSH Server on Hank Rearden, admin/standard-user authorized_keys paths, ssh alias in ~/.ssh/config, warning about Dropbox Selective Sync excluding the Stormy 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
    * Ch 20.6 Tier 4a and Tier 4b workflows updated: SSH-alias-based scp is primary, FileZilla drag-drop r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
2026-09-14 backup infra: probe Hank Rearden with 'exit 0' (Unix-only 'true' fails on Windows OpenSSH)
2026-09-14 FN 107: Windows OpenSSH server needs 'exit 0' not 'true' for reachability probes
2026-09-14 verify_images.sh + diskbackup --verify chain (Ch 20.4)
2026-09-21 v1.2 amend 2026-09-21: right rear Power Input Panel rewire caught up
    Manual:
    - Ch 2.2 Protection line: 15SQ045 pair (was single STPS10L25D)
    - Ch 3.1 Topology: header 'target/in progress' -> 'current, 2026-09-20',
    Status paragraph deleted; topology diode annotation swap to 15SQ045
    with terminal-strip cross-ref
    - Ch 3.1 'Fuse-holder proto-board' section rewritten as 'Right rear
    Power Input Panel (2026-09-20, as-built)' - dual PowerPoles, panel
    fuse, 12-pos terminal strip carrying the OR-ing diode pair, RJ45
    keystone jack, bench diode-block field-verification note, four
    assembly photos in stingray build repo, KiCad source refs, and a
    short historical paragraph preserving the pre-r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
    [Dual Power Input.kicad_sch, Stingray.kicad_sch]
2026-09-27 v1.2 amend 2026-09-27: Panel hot-swap verified + bench-power indicator LED
    - Title block: second amendment entry for 2026-09-27
    - Ch 3.1: new 'Green power-source indicator LED' bullet in Panel
    description (bench input side only; ferrule sizing; no battery-side
    indicator needed); new 'Post-install hot-swap verification' paragraph
    documenting the successful swap AND the bench-PSU output-button gotcha
    that killed the Pi on first attempt; Photographs list updated to the
    current filenames (LED front/back/illuminated + LED schematic)
    Field Notes:
    - FN 22 gains 'Bench-power indicator LED lesson (2026-09-27)' sub-section:
    full narrative of the failed first swap, why the bench PS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
2026-10-03 tools/backup_check: probe /proc/mounts for STORMYBAK so an unplugged weekly HDD warns instead of hanging on autofs
    The Tier-2 check called 'mountpoint -q /mnt/backup', but /mnt/backup is a
    systemd autofs path. With the weekly STORMYBAK HDD unplugged, that call
    triggered the automount and blocked until the autofs timeout, hanging the
    daily 'backup' run. Now probe /proc/mounts for a real (non-autofs) mount,
    which never triggers autofs; an absent HDD just warns and skips.

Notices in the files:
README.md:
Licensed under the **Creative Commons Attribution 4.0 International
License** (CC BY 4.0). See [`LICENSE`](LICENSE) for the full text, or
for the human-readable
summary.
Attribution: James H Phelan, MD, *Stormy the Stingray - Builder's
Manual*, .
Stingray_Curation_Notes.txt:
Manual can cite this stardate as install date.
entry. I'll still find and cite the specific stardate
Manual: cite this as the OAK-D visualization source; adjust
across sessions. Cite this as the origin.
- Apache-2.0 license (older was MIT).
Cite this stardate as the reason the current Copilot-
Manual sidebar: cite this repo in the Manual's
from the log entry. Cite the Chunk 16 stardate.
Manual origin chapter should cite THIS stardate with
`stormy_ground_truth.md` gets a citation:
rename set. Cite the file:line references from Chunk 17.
